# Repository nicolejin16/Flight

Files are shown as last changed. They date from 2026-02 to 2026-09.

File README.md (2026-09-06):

# SN
---
WRO documentation
<div align="center">
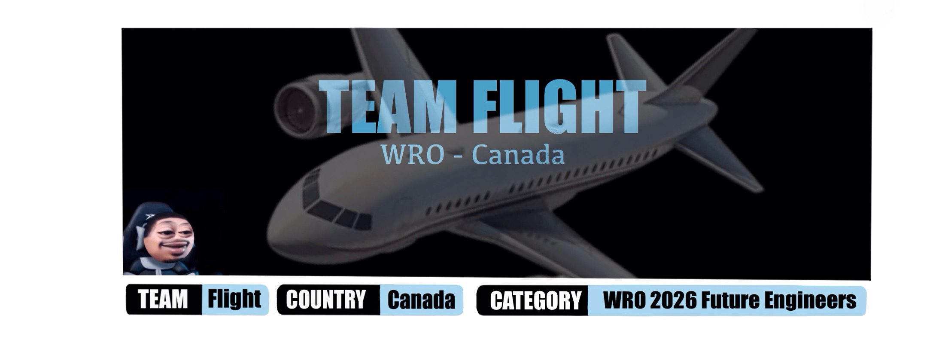
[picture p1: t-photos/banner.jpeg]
teamflightbanner

</div>

[WRO Engineering Journal 2026 - Nicole and Summer (PDF)](./Engineering%20Journal.pdf)

# Introduction
Team Flight is a group of high-school students from Ontario, Canada. This is our second year participating in WRO Future Engineers. We are passionate about robotics and is excited to compete in the open challenge and obstacle challenge for 2026. Our objective is to improve our score and documentation from last year and build a robot using hardware such as a LiDAR, Raspberry Pi 5, and new technology introduced to us like the Arduino Nano.

# Our coach
<table>
<tr>
  <td align="center" width="40%">
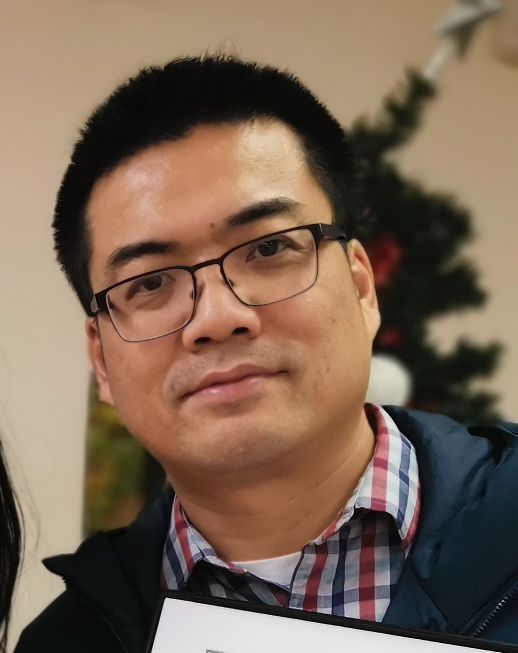
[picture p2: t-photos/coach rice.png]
    <br>
  </td>

  <td valign="top" width="60%">
 - Head coach of Robotics Competitions, including FLL (First LEGO League),  WRO (World Robotics Olympiad) Robo Sports, Future Engineers, and Robo Mission. Led teams in winning multiple national, international robotics, and programming awards. <br>
  - MSc in Electrical & Computer Engineering from the University of Alberta. <br>
  - BSc in Mathematics from Peking University.<br>
  - Founder of Explorer Robotics, a local robotics club in Ajax and Whitby, teaching coding, AI, robotics, etc.
  </td>
</tr>
</table>

# Team Members
---
<table width="100%" style="border:2px solid #FFC107; border-radius:12px; margin:12px 0;">
  <tr>
    <td width="28%" align="center" style="padding:12px; border-right:6px solid #111;">
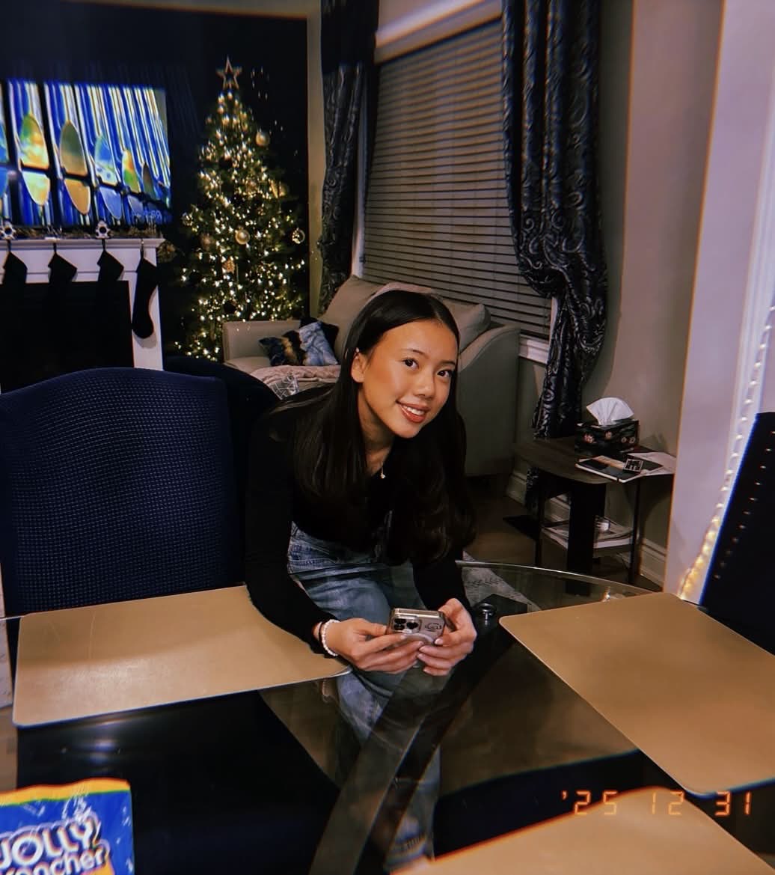
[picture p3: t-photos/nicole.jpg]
Nicole
    
    </td>
    <td width="72%" style="padding:12px 16px;">
      <h3 style="margin:0 0 6px 0;">Nicole - nicolejin27@gmail.com</h3>
      <p style="margin-top:8px;">
        <b>About Me:</b> My Name is Nicole, I am 16 years old. I am a figure skater and I also do badminton and track and field for my school. I have been involved in coding and Explorer Robotics since I was 8 and did WRO Future Engineers last year as well.
      </p>
    </td>
  </tr>
</table>

<table width="100%" style="border:2px solid #FFC107; border-radius:12px; margin:12px 0;">
  <tr>
    <td width="28%" align="center" style="padding:12px; border-right:6px solid #111;">
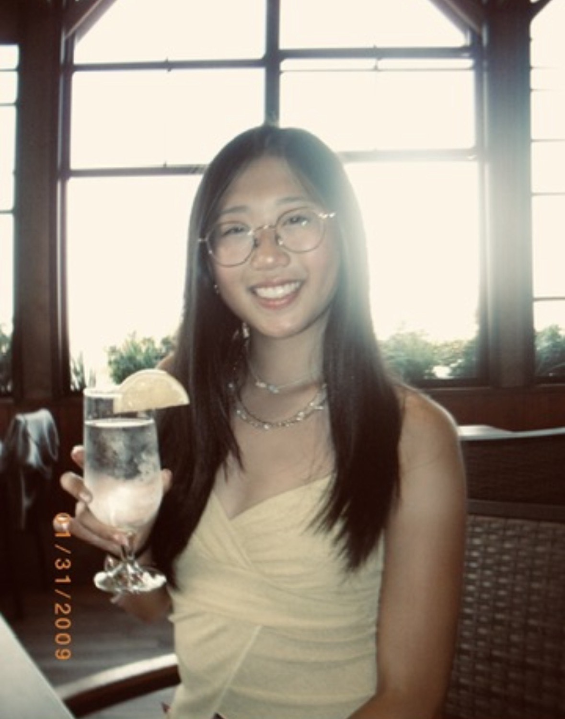
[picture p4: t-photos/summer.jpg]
Summer
    
    </td>
    <td width="72%" style="padding:12px 16px;">
      <h3 style="margin:0 0 6px 0;">Summer - summerlyu@gmail.com</h3>
      <p style="margin-top:8px;">
        <b>About Me:</b> My name is Summer, I am 17 years old. I love figure skating and drawing. I also do badminton, alpine skiing, and track and field for school. I starting coding when I was twelve years old and this is my second year doing WRO Future Engineers. 
      </p>
    </td>
  </tr>
</table>

# Team Photo

<table width="100%" style="border:2px solid #FFC107; border-radius:12px; margin:8px 0;">
  <tr>
    <td align="center" style="padding:14px;">
      <div style="border:2px dashed #FFC107; border-radius:10px; padding:24px; height:320px; display:flex; align-items:center; justify-content:center;">
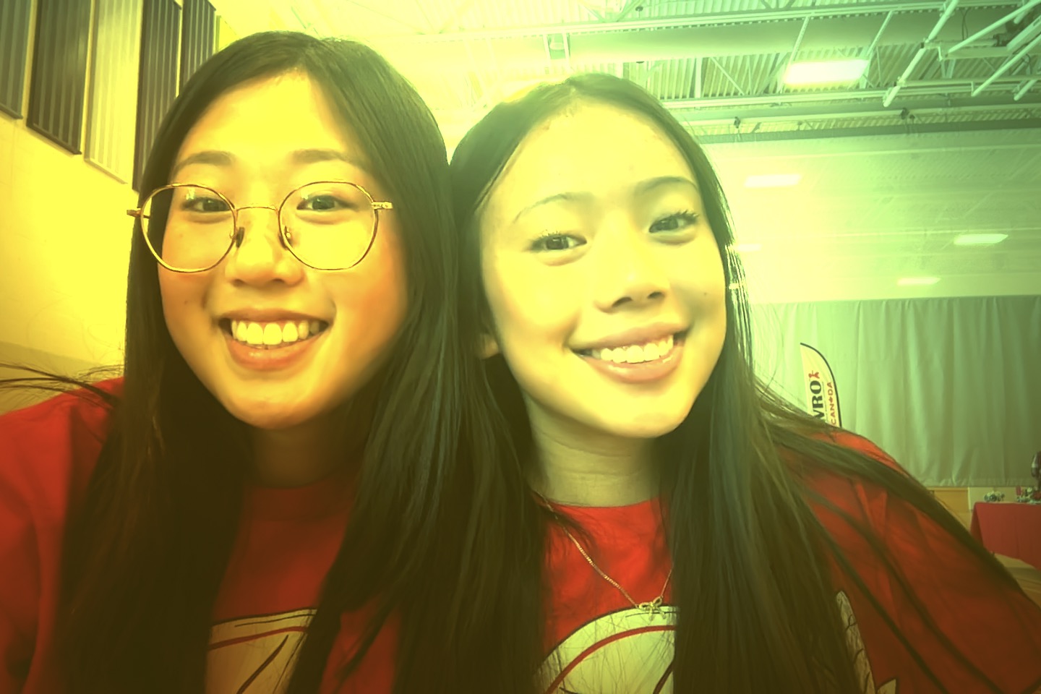
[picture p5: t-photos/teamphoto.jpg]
        <b></b>
      </div>
      <div style="margin-top:8px; color:#444;"><em>Team Flight</em></div>
    </td>
  </tr>
</table>

</div>

</br>
More team photos are provided in the "t-photos" folder. 

---

</br>

# Complete construction manual
The WRO Future Engineers is a competition for self-driven vehicles. Students need to design a model of a car, equip it with electromechanical components, and program it so that it can drive autonomously on the track, avoiding obstacles.
More details about the competition can be found on [the official site of WRO Association](https://wro-association.org/competition/2025-season/#rules).

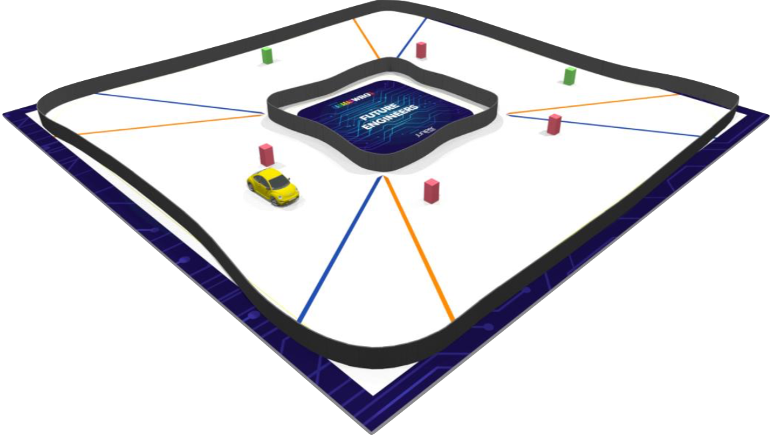
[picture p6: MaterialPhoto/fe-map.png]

The materials are intended to be built with the [Mkdocs](https://www.mkdocs.org/) site generator.

The example of the site is accessible [here](https://world-robot-olympiad-association.github.io/future-engineers-gs/)

# Hardware
---
| Name | Product | Price (CAD)|
| --- | --- | --- |
| RC Car Battery | [`Gens Ace 1300mAh Battery`](https://genstattu.com/gens-ace-1300mah-2s-7-4v-45c-g-tech-lipo-battery-pack-with-deans-plug/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) | $20.60 | 
| Drive Motor | [`Furitek Micro Komodo 1212 3450KV Brushless Motor`](https://furitek.com/products/furitek-micro-komodo-1212-3456kv-brushless-motor-with-15t-steel-pinion-for-fury-wagon-fx118) | $35.00 |
| Servo Motor | [`HS-5055MG 11.9g Metal Gear Digital Micro Servo`](https://hitecrcd.com/hs-5055mg-economy-metal-gear-feather-servo/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) | $25.00 |
| ESC | [`Furitek Lizard Pro 30A/50A ESC`](https://furitek.com/products/combo-of-furitek-lizard-pro-30a-50a-brushed-brushless-esc-for-axial-scx24-with-bluetooth) | $80.00 |
| Camera | [`5MP 1080P HD Camera with OV5647 Sensor`](https://www.amazon.ca/dp/B0D324RKRZ?ref=ppx_yo2ov_dt_b_fed_asin_title) | $35.00 |
| Raspberry Pi 5 8GB | [`Raspberry Pi 5`](https://www.amazon.ca/RasTech-Raspberry-Pi-refroidisseur-inclus/dp/B0DQX6JPVM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) | $250.00 |
| Arduino | [`Arduino Nano 33 BLE Rev2`](https://www.digikey.ca/en/products/detail/arduino/ABX00071/22478340) | $33.41 |
| Chassis | [`Gyro Version Drift car 1:24 scale`](https://www.aliexpress.com/item/1005010792530908.html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) | $163.05 | 
| LiDAR | [`LDROBOT D500 LiDAR Kit`](https://ca.robotshop.com/products/hiwonder-ld19-d500-lidar-developer-kit-360-dtof-laser-scanner-supports-ros1-2-raspberry-pi-jetson-nano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) | $149.99 |
| Button | [`2 Pin Panel Push Button`](https://www.amazon.ca/dp/B01J9KO7DC?ref=ppx_yo2ov_dt_b_fed_asin_title&th=1) | $12.99 |
| Switch | [`DC AC rocker switch`](https://www.amazon.ca/Suitable-125V-250V-Motorcycle-Disconnect-Dispenser/dp/B087PYW9BS) | $5.99 |
| Power regulator | [`Power supply expansion board for raspberry pi 5`](https://ca.robotshop.com/products/yahboom-power-supply-expansion-board-raspberry-pi-5) | $17.54 |

**Total:** $828.57
**With Tax:** $936.28

## Mobility

- [ESC](#ESC)
- [Servo motor](#Servo-motor)
- [Drive motor](#Drive-motor)
- [Power regulator](#Power-regulator)
- [Chassis](#Chassis)
- [Steering and Drive system](#Steering-and-drive-system)

## Power
- [RC car battery](#RC-car-battery)
- [Ratings and Wiring](#Ratings-and-wiring)

## Sensors and Perception
- [Camera](#Camera)
- [Raspberry pi 5](#Raspberrypi-5)
- [Arduino](#Arduino)
- [LiDAR](#LiDAR)

## Extra
- [Switch](#Switch)
- [Button](#Button)

## Code
- [Open Challenge](#Open-Challenge)
- [Obstacle Challenge](#Obstacle-Challenge)

# Mobility 

## ESC
<table>
<tr>
  <td valign="top" width="35%">

 ### Physical Qualities
  | Field          | Value                              |
  |----------------|------------------------------------|
  | **Product Title** | Furitek Lizard Pro 30A/50A ESC   |
  | **Size**          | 28 × 15.5 mm                     |
  | **Weight**        | 3.7 g                            |

  </td>

  <td width="65%" align="center">
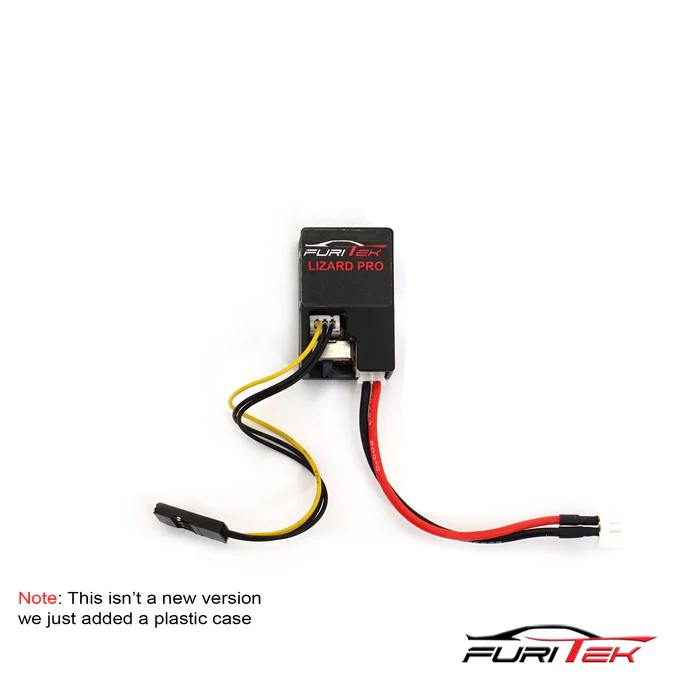
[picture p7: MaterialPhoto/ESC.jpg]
    <br>
    <em>Furitek Lizard Pro 30A/50A ESC</em>
  </td>
</tr>
</table>

### Why we chose this product

We chose Furitek Lizard Pro ESC because it controls the motors speed and ensure that voltage and current is safely delierved to the motor. It's small and manages direction on the open challenge and obstacle challenge. This ESC has a lightweight design, a high capacity and a reliable built-in BEC.

---

### Addtional information
- BIG BEC: **5V or 5V 2.5A**  
- Constant current : **30A**  
- Burst current: **50A**

[click here to return to links](#mobility)

## Servo motor
<table>
<tr>
  <td valign="top" width="35%">

### Physical Qualities
  | Field          | Value                                             |
  |----------------|---------------------------------------------------|
  | **Product Title** | HS-5055MG 11.9g Metal Gear Digital Micro Servo |
  | **Size**          | 0.89 x 0.45 x 0.94 inches                      |
  | **Weight**        | 9.5 grams                                      |
  | **Motor Type**    | 3 Pole Metal Brush Ferrite                     | 

  </td>

  <td width="65%" align="center">
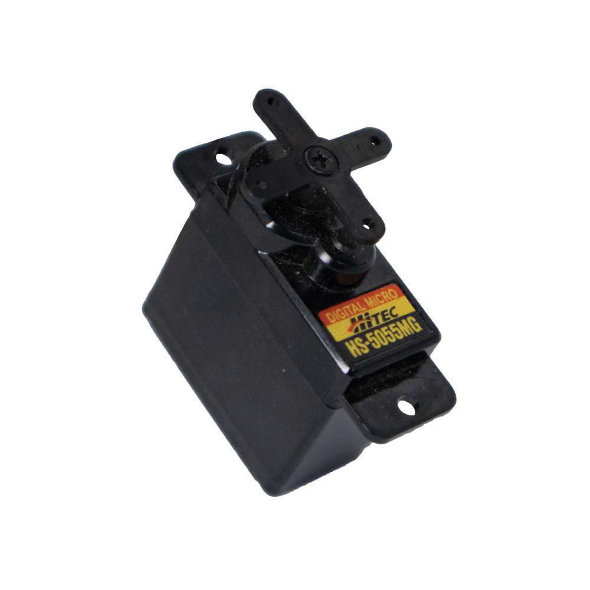
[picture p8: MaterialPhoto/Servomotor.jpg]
    <br>
    <em>HS-5055MG 11.9g Metal Gear Digital Micro Servo</em>
   </td>
</tr>
</table>

### Why we chose this motor 
We chose the Metal Gear digital Micro Servo because it has metal gears, which can withstand sustained high-speed voltage. It also has plastic casing around it which makes it light. Its compact and gives 1.3 ~ 1.6 kg./cm as maximum torque making it smooth and fast. 

### Additional information
- Operating Voltage Range: **4.8V ~ 6.0V**  
- Speed (Second @ 60°): **0.20 ~ 0.17**  
- Maximum Torque Range oz. / in.: **18 ~ 22**  
- No Load Operating Current draw: **120mA**    

</td>
</tr>
</table>

[click here to return to links](#mobility)

## Drive motor
<table>
<tr>
  <td valign="top" width="35%">

 ### Physical Qualities
  | Field          | Value                              |
  |----------------|------------------------------------|
  | **Product Title** | Furitek Micro Komodo 1212 3450KV |
  | **Size**          | 15.5 × 20.6 mm                   |
  | **Weight**        | 17.5 g                           |
  | **Physical State**| Brushless Outrunner (12-slot)    |

  </td>

  <td width="65%" align="center">
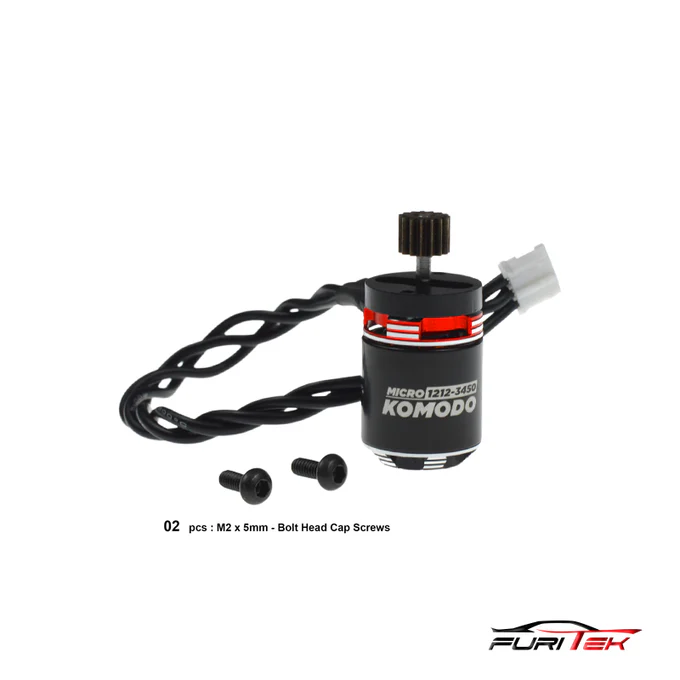
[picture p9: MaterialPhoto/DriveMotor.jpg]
    <br>
    <em>Furitek Komodo 1212 motor</em>
  </td>
</tr>
</table>

### Why we chose this motor 

We chose Furitek Micro Komodo brushless motor because its very compact and light-weight making it easier for our car to manouver. It distrbutes torque smoother and more evenly which helps less cogging and better control. 

---

### Addtional information
- KV: **3450 rpm/V**  
- No-load @10V: **0.7 A**  
- Power: **120 W**  
- Battery: **2–3S LiPo**  
- Resistance: **0.16 Ω**  
- Max Current: **10 A**  
- Slot/Pole: **12**  
- Shaft: **1.5 × 6 mm**

[click here to return to links](#mobility)

## Power regulator
<table>
<tr>
  <td valign="top" width="35%">

 ### Physical Qualities
  | Field          | Value                              |
  |----------------|------------------------------------|
  | **Product Title** |  Power supply Expansion board for Raspberry Pi 5  |
  | **Weight**        |      32g                           |
  | **Size**          |      65 by 56mm                 |

  </td>

  <td width="65%" align="center">
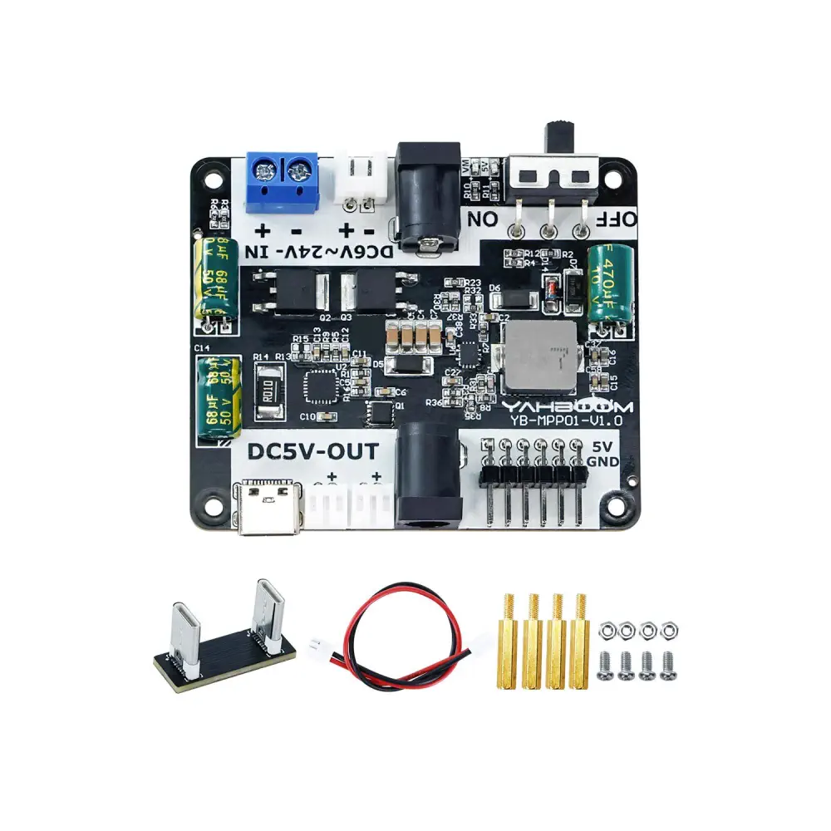
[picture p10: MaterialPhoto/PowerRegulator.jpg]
    <br>
    <em>Power regulator</em>
  </td>
</tr>
</table>

### Why we chose this product
We chose this power supply expansion board because it was tailor made for raspberry-pi. It has many input and output ports and it has efficient voltage stabilization technology, ensuring that the input power supply is stably adjusted for the 5V/5A output, which meets the power needs for the raspberry pi perfectly. Using this power regulator prevents potential low-voltage operation risks and USB interface current limitation. It can also stack directly onto the raspberry pi with screw copper posts, which makes our car more compacts and easier to turn. 

---

### Addtional information
- Voltage input: **6~24V**
- Voltage output: **5V/3A (6V Input), 5V/5A (7~24V input)**
-  Output interference: **Type-C, PH2.0-2pin*2, DC5.5*2.1, 2*6pim Bent pin header**
-  Through hole diameter: **M2.5mm**

[click here to return to links](#mobility)

## Chassis
<table>
<tr>
  <td valign="top" width="35%">

 ### Physical Qualities
  | Field          | Value                              |
  |----------------|------------------------------------|
  | **Product Title** |    RC Drift Car 1:24 Scale |
  | **Weight**        |      110g                           |
  | **Size**          |       21 x 9.5 x 6 cm               |

  </td>

  <td width="65%" align="center">
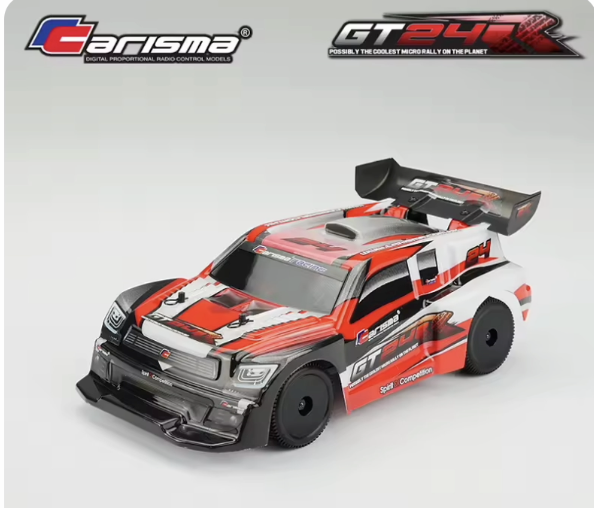
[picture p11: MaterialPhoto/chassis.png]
    <br>
    <em>  RC Drift Car 1:24 Scale</em>
  </td>
</tr>
</table>

### Why we chose this product
We chose this chassis because it was easy to take apart and use as a sturdy base for our robot. It was lightweight and many parts could easily be taken apart to make space for the motors and battery to fit inside. Its dimensions are long enough to include every component, but doesn't hinder the functionality of the robot. The wheels are made of grippy materials, making the robot be able to turn easily and with accuracy. The base if flat, making it easy to mount our 3D printed pieces that hold up our camera and raspberry Pi. 

### Placement choice for components
- The camera is placed at a level where it's able to see incoming walls, pillars, and obstacles at a reasonable distance without being to high causing an imbalance. It's placed at an angle where it includes the space in front of the robot, but not what on the robot.
- The LiDAR is placed at the front of the robot to ensure it is detected well in advance so our robot is prepare to avoid the oncoming obstacle from all directions. By placing it in the front, it doesn't need to calculate the difference between the obstacle and the bumper. Placing the LiDAR at a low point prevents anything from blocking the sensors. 
- By putting the motors, esc, and battery close together under the raspberry Pi, it reduces the amount of wires around the robot, making it more organized and clean. We can also place the wires underneath, saving space and preventing it from getting in the way or getting loose.

---

### Addtional information
- Ranging Distance: **0.03-12m**

[click here to return to links](#mobility)

## Steering and drive system
### Steering
Our chassis didn't have a large enough steering angle, but with many adjustments, we hollowed a larger compartment and cut limitations so our chassis can turn sharper around pillars and corners. In the hollowed compartment, we put both our motors, keeping it compact and saving space. 

- Both left and right wheels turn at the same angle, reducing imbalance and oversteering.
- By keeping it compact more of the weight is focused lower, making uncontrolled movement minimized and more predictable steering.
- Larger steering angle makes last minute navigation easier around pillars and walls. 

### How the car moves 

When the battery provides power, the ESC manages the electricity sent to the motor. The motor turns this controlled flow of electricity into rotational motion, which makes the car's wheels spin. By changing the voltage and current through the ESC, we can control the car's speed and direction, enabling it to move forward, backward, accelerate, slow down, or reverse.

At the same time, the servo motor handles steering. It changes the angle of the front wheels through the steering system, allowing the car to turn left or right accurately.

### Drive system 
Our car uses a real whieel drive (RWD), meaning that the motor's power is transmitted to the back wheels rather than the front. This configuration provides many benefits to the car:
- Better weight distribution. The front wheels handle all the steering, and the rear wheels help with propulsion, whith helps the car remain more balanced when accelerating and turning. 
- Provides a stronger grip on surfaces such as the map. Since the rear of the robot has more weight, the back wheels get pressed down into the ground more, providing more traction and grip. 
- The front wheels are used only for steering, this is so the car can turn more precisely aince theres no interference from the motor. 
<br>

[click here to return to links](#mobility)
# Power

## RC car battery
<table>
<tr>
  <td valign="top" width="35%">

  ### Physical Qualities
  | Field | Value |
  |--------|--------|
  | Product Title | Gens Ace 1300mAh 2S 7.4V 25C LiPo |
  | Size | 70.9 × 35.2 × 14.5 mm |
  | Weight | 90 g |

  </td>

  <td align="center" width="65%">
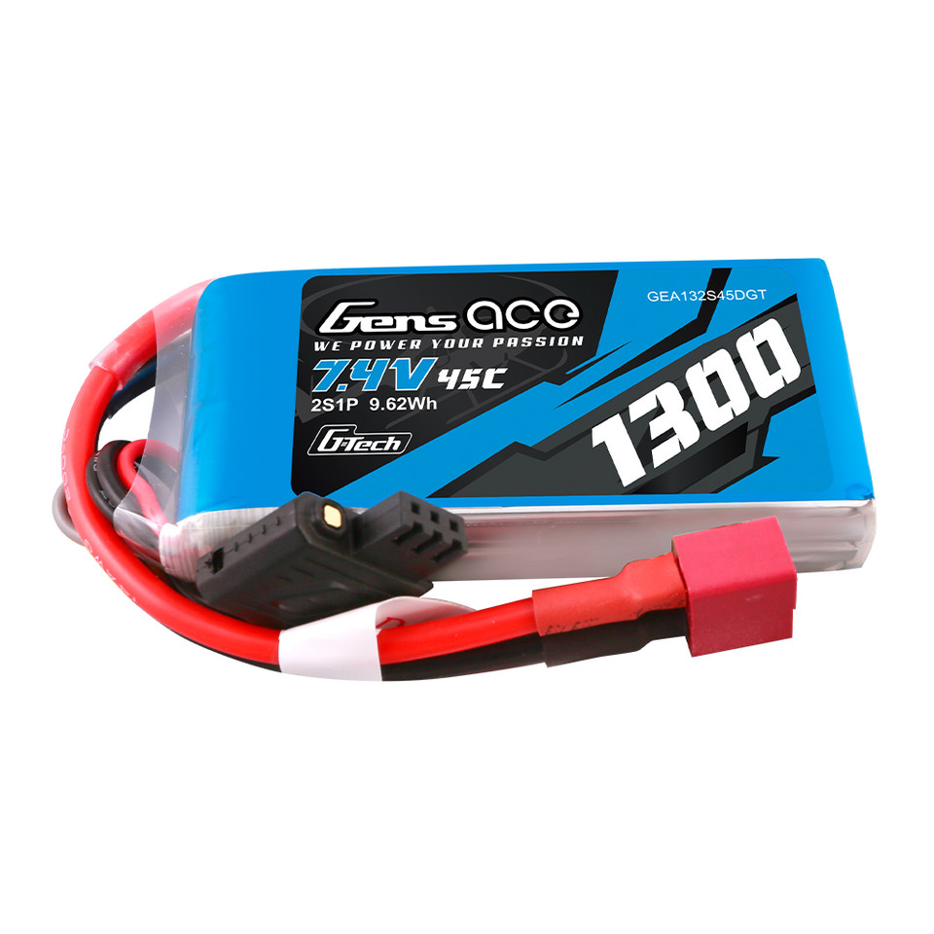
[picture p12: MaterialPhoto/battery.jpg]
    <br>
    <em>Gens Ace 1300mAh 2S LiPo Battery</em>
  </td>
</tr>
</table>

### Why we chose this battery
We chose the Gens Ace Battery because its lightweight and provides a long run time between charges. 
It allows us to keep the self-driving car well balanced which is optimal for the obstacle challenge and open challenge. 
The 7.4V gives good acceleration without noticeable voltage drop and offers stable power delivery without extra wear. 

---

### Additional information
- Voltage: **7.4V**  
- Capacity: **1300mAh**  
- Discharge Rate: **45C Continuous / 90C Peak**  
- Charge Rate: **5C (6.5A Max)**
- Cell Configuration: **2S1P**  
- Watt Hours: **9.62Wh**  

The battery is secured to our robot by tape on the bottom. <br>
[click here to return to links](#mobility)

---

##  Ratings and wiring

### Power ratings table

| Component | Voltage | Normal Current Draw | Max Current Draw | Normal Power | Max Power |
|-|-|-|-|-|-|
| Camera | 5 V | 0.16 A | 0.20 A | 0.80 W  | 1.00 W  |
| Furitek Lizard Pro ESC | 7.4 V | 0.007 A  | 0.10 A | 0.05 W  | 0.74 W  |
| Furitek Micro Komodo Motor  | 7.4 V | 0.95 A | 10.0 A | 7.00 W  | 74.0 W  |
|  Servo Motor | 5 V | 0.10 A | 0.70 A | 0.50 W  | 3.50 W  |
| MicroSD, LEDs, | 5 V | 0.12 A | 0.30 A | 0.60 W  | 1.50 W  |
| Raspberry Pi 5 | 5 V | 0.55 A | 2.00 A | 2.75 W  | 10.0 W  |
| Expansion Board | 5 V | 0.12 A | 0.50 A | 0.60 W  | 2.50 W  |

<br>

Our Gens Ace 1300 mAh 7.4V  Lipo Battery provides plenty of power to our car as shown in the power ratings table above/ 
This will ensure that all our properties will run smoothly and provide stable voltage for the Raspberry Pi, controller, sensors, and periherals. <br>

**Estimated runtime (Idle/bench testing):** 45-60 minutes 
- The robot is stationary. The LiDAR is actively scanning, the camera is streaming, the Pi is idle or listening for commands, and the servo is holding its position.
- Logic Load (i.e. camera, Pi, arduino): 1.2A @ 5V (6.0W)
- Mechanical Load (i.e. servo): 0.1A @ 5V (0.5W)
- Total Power Consumption: 6.5W <br>

**Estimated runtime (Active driving run):** 20-28 minutes 
- Logic load (Pi is working harder): 1.8A @5V (9.0W)
- Mechanical Load (Motor moving + steering adjustments): 2.0A @ battery voltage (Avg. approx 18W)
- Total Power Consumption: 27.0W <br>
**Estimated runtime (Heavy/High Load):** 18-22 minutes 
- Logic Load (using max Pi and camera utilization): 2.4A @ 5V (12.0W)
- Mechanical Load (Heavy motor draw + hard servo cornering): 6.0A continuous average @ battery voltage (approx 55W - 65W)
- Total Power Consumption: 72.0W <br> <br>
### Electrical wiring
<div algn="center">
<table>
  <tr>
    <td style="border: 200px solid black; padding: 5px;">
      
    </td>
  </tr>
</table>

</div>

### Components

- Raspberry Pi 5
- Expansion Board
- Camera
- Servo Motor
- ESC (Electronic Speed Controller)
- Motor
- Battery
- Switch

[click here to return to links](#mobility)

# Sensors and Perception

## Camera
<table>
<tr>
  <td valign="top" width="35%">

 ### Physical Qualities
  | Field          | Value                              |
  |----------------|------------------------------------|
  | **Product Title** | 5/Zero Camera Module (OV5647 Sensor)   |
  | **Cable**         | 15 cm Ribbon Cable                     |
  | **Weight**        | 20 g                                   |
  | **Size**          | 11.6 x 6.6 x 3.7 cm                    |

  </td>

  <td width="65%" align="center">
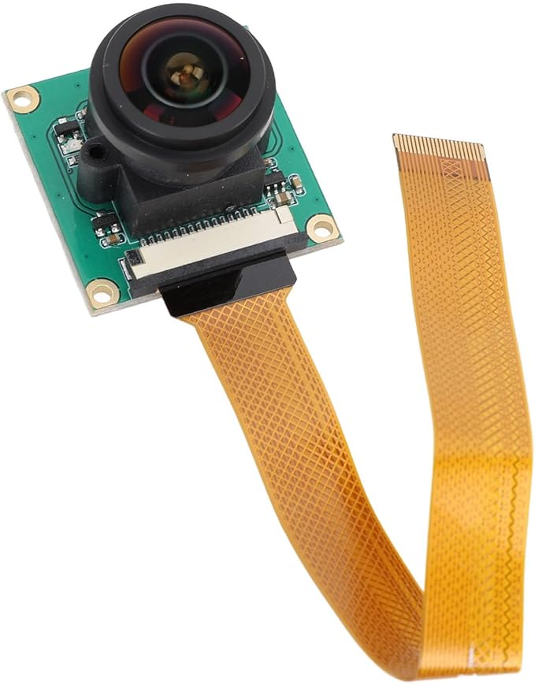
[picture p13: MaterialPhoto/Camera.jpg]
    <br>
    <em>5/Zero Camera Module (OV5647 Sensor)</em>
  </td>
</tr>
</table>

### Why we chose this product

We chose the 5/Zero Camera Module because we can use the wide angle camera lens to track the regions of interest and limit the amount of blind spots during the open challenge. It's 175° lens is good for wall detection and true to life colors with automatic light adjustment. It's very compatible with the raspberry pi and easy to install. It can withstand heat up to 70° celcius, making it suitable when we need to use it for longer periods of time. 

---

### Addtional information
- Material: **ABS+ Optimal glass**  
- Lens Pixel : **5MP**  
- Focal Length: **3.6mm**
- Lens Angle: **175°**
- CMOS Size: **1/2.5inch**
- Resolution: **2592x1944**

[click here to return to links](#mobility)

## Raspberrypi 5
<table>
<tr>
  <td valign="top" width="35%">

 ### Physical Qualities
  | Field          | Value                              |
  |----------------|------------------------------------|
  | **Product Title** | RasTech Raspberry Pi 5 Kit (8GB RAM)   |
  | **Weight**        | 70 g                                  |
  | **Size**          | 15 x 9.9 x 3.9 cm                      |
  | **Comes with**    | Pi 5 Board, Case, Active Cooler, Screwdriver |

  </td>

  <td width="65%" align="center">
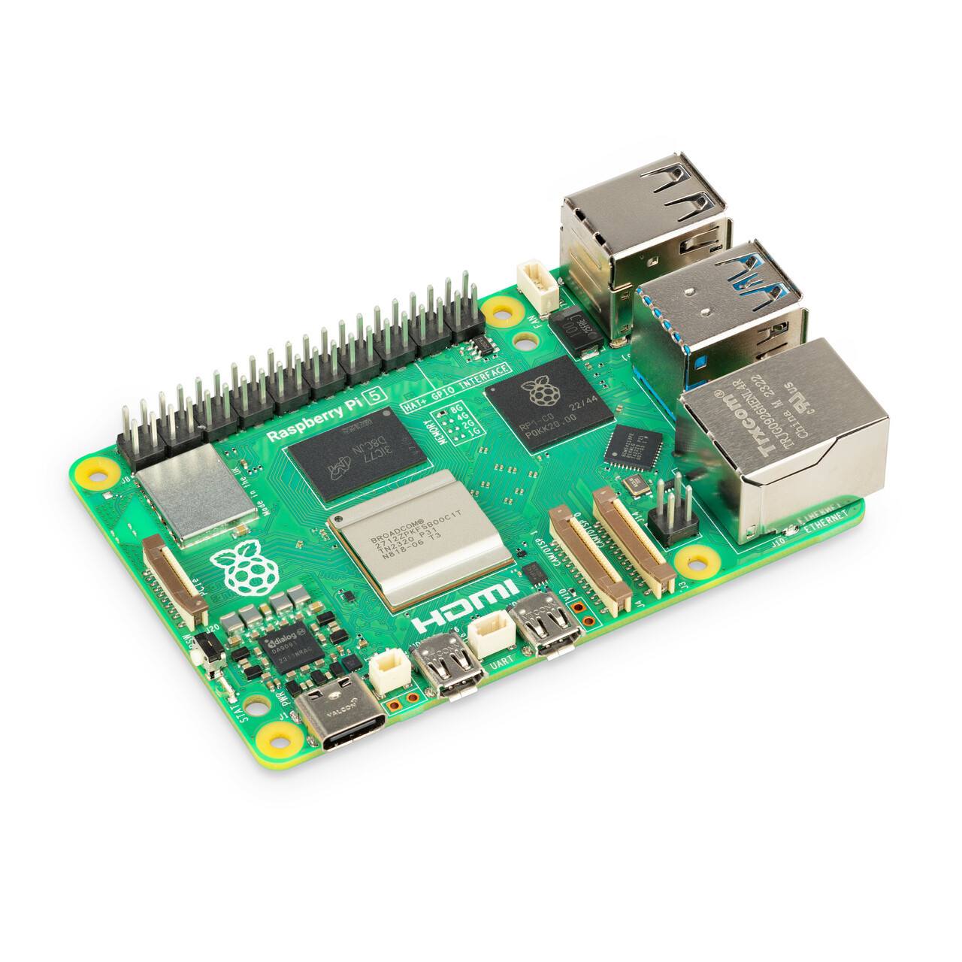
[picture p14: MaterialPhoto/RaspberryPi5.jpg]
    <br>
    <em>RasTech Raspberry Pi 5 Kit (8GB RAM)</em>
  </td>
</tr>
</table>

### Why we chose this product

The main part of our robot is the Raspberry Pi 5 and it controls the computer vision and LiDAR data interpretation. It is perfect for energy comsumption and processing power, making it suitable for running our Python codes for the open challenge and obstacle challenge. 

---

### Addtional information
- Manufacturer: **Vemico**  
- Wireless : **802.11ac Wi-Fi, Bluetooth**  
- Processor: **Broadcome BCM2712, Quad-Core Cortex-A76 @ 2.4 GHz**
- RAM: **8 GB LPDDR4X-4266**
- GPU: **VideoCore VII (Integrated)**
- Storage: **microSD**
- Ports: **2x USB 3.0, 2x USB 2.0, 2x micro HDMI, Ethernet, GPIO**
- OS: **Raspberry Pi OS**

[click here to return to links](#mobility)
  
## Arduino
<table>
<tr>
  <td valign="top" width="35%">

 ### Physical Qualities
  | Field          | Value                              |
  |----------------|------------------------------------|
  | **Product Title** |   Arduino nano 33 BLE REV2 |
  | **Weight**        |  5g                                  |
  | **Size**          |   45mm x 18mm                 |

  </td>

  <td width="65%" align="center">
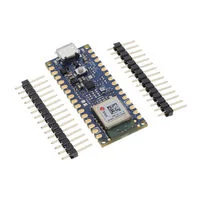
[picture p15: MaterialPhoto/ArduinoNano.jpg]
    <br>
    <em> Arduino nano 33 BLE REV2</em>
  </td>
</tr>
</table>

### Why we chose this product
The 4 PWM pins makes it versatile for various embedded applications/ It's super compatible with the arduino IDE, making the programming smooth and seamless. It weighs only 5 grams which minimizes load on the chassis, allowing for better acceleration and agility. 

### How the arduino and raspberry Pi communicate
The Raspberry Pi handles the LiDAR's mapping, vision processing, and path planning while offloading low-level GPIO operations (ESC PWM signaling, steering servo adjustments, wheel encoder interrupts) to the Nano. Connecting the Arduino Nano directly to the Pi 5's USB 3.0 port provides both power and a clean USB-Serial interface without needing external voltage level shifters. The Pi 5's GPIO pins strictly operate at 3.3V. Interfacing 5V sensors directly through the Nano's native 5V-tolerant analog/digital pins prevents accidental overvoltage damage to the Pi. 

---

### Addtional information
- Logic level voltage: **3.3V**
- Input voltage: **5V to 18V**
- Digital I/O Pins: **14**
- Clock speed: **64 MHz**
- Flash memory: **1MB**

After we soldered the arduino, it was secured tightly to our robot using double sided tape on the USB ports of the raspberry pi. <br>
[click here to return to links](#mobility)

## LiDAR
<table>
<tr>
  <td valign="top" width="35%">

 ### Physical Qualities
  | Field          | Value                              |
  |----------------|------------------------------------|
  | **Product Title** | LDROBOT D500 LiDAR   |
  | **Weight**        | 45 g                                  |
  | **Size**          | 54 × 46.3 × 35 mm                     |

  </td>

  <td width="65%" align="center">
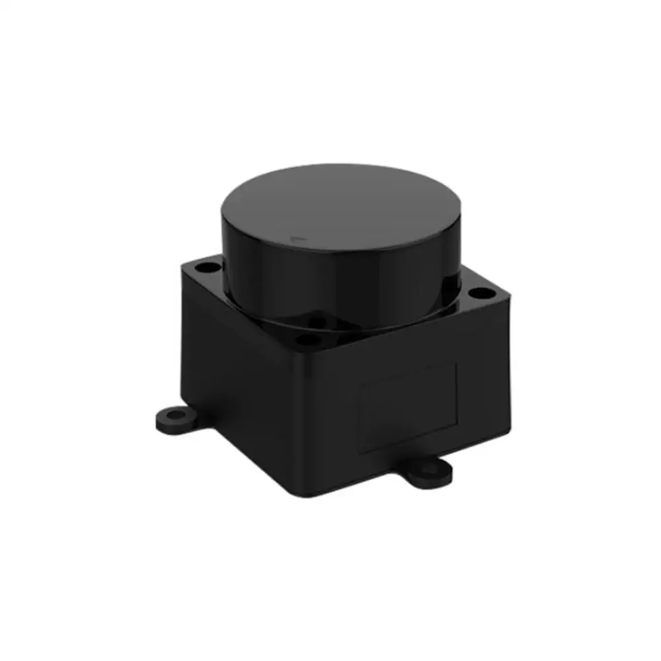
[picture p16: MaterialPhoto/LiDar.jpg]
    <br>
    <em>LDROBOT D500 LiDAR </em>
  </td>
</tr>
</table>

### Why we chose this product

 We are going to use the LDROBOT D500 LiDAR for obstacle challenge because it provides accurate range data in every direction up to 12 meters. We are also switching to use the LiDAR instead of the camera because it doesn't depend of good lighting to function properly. With its long scanning range, it can detect obstacles further away and then turn accordingly. 

### Parking
We have planned on using the LiDAR for the parallel park section at the beginning and end of the obstacle challenge, but we haven't had the change to progress that far this year. We have the placement and layout for the use of the LiDAR and we will continue to work on its use and progression in the future. So, we are not going to be using the LiDAr for the obstacle challenge this year. 

---

### Addtional information
- Ranging Distance: **0.03-12m**  
- Accuracy : **±10 mm (0.3–0.5 m), ±20 mm (0.5–2 m), ±30 mm (2–12 m)**  
- Scanning Angle: **360°**
- Scanning frequency: **6-13 Hz**
- Ranging frequency: **5000Hz**
- Wavelength: **895 – 915 nm (Typ. 905 nm)**
- Interface: **UART @ 230400 baud**
- Ambient Light Tolerance: **up to 60k Lux**
- Power Supply: **5V**
- Power Comsumption: **1.45W (290 mA)**
- Operating Temp: **-10° to 45° C**

[click here to return to links](#mobility)

# Extra
  
## Button
<table>
<tr>
  <td valign="top" width="35%">

 | Field          | Value                              |
  |----------------|------------------------------------|
  | **Product Title** |   2 Pin Panel Push Button |
  | **Weight**        |            22.68 g                |
  | **Size**          |     16.51 x 0.51 x 0.51 cm   |
  |**Brand**          |   MakerSpot  |
  | **Material**      |  tile |

  </td>

  <td width="65%" align="center">
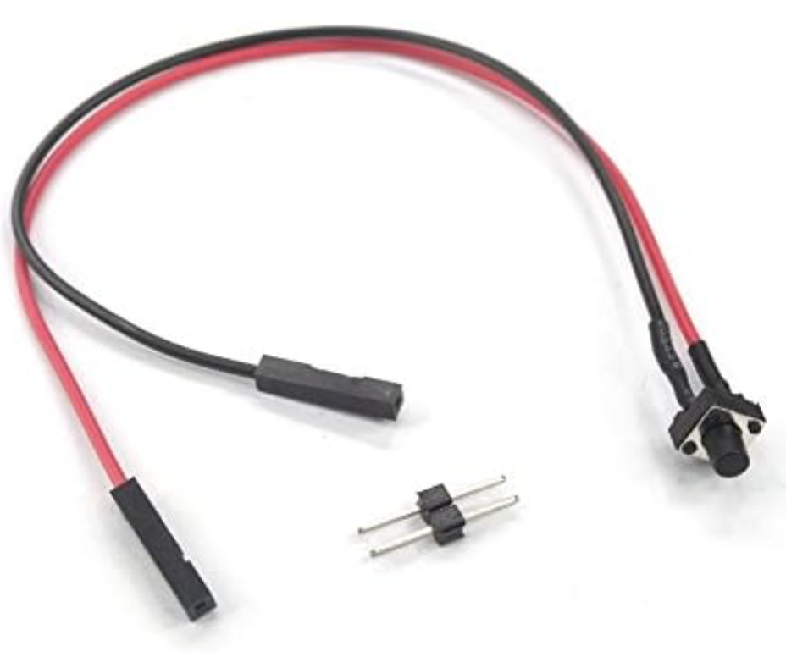
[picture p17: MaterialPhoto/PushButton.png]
    <br>
    <em>2 pin push button</em>
  </td>
</tr>
</table>

### Why we chose this product
We chose this button for our raspberry Pi because it's very simple yet easy incorporate onto our robot. Since adding this button was a last minute detail, it's lightweight and small design allows an easy attachment without getting in the way of the other robot components. 

---

### Addtional information
- Current rating: **50 milliamps**
- Terminal: **solder**
- Contact material: **copper**
- Mounting type: **through hole mount**
- Operating mode: **manual**
  
[click here to return to links](#mobility)
## Switch
<table>
<tr>
  <td valign="top" width="35%">

 | Field          | Value                              |
  |----------------|------------------------------------|
  | **Product Title** |  DC AC rocker switch  |
  | **Weight**        |        4g                    |
  | **Size**          |    1.1cm by 2.1cm by 1.5cm      |
  |**Brand**          |  	EKYLIN   |
  |**Material**       | Metal, plastic  |

  </td>

  <td width="65%" align="center">
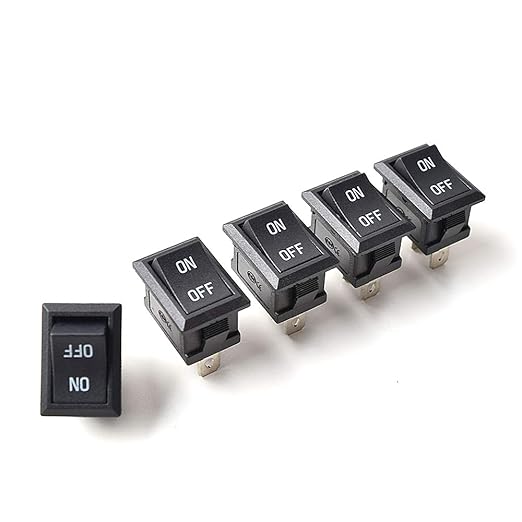
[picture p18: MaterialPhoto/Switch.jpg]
    <br>
    <em>DC AC rocker switch</em>
  </td>
</tr>
</table>

### Why we chose this product
We choose this switch because it was simple and easy to install. This switch is suitable for AC 125V 10A, AC 250V 6A, DC 12V 20A, DC 24V 10A, DC 36V 6.5A. It was made by an insulated plastic and copper pins, with a mechanical life of more than 8 thousand cycles and an electrical life of more than 10 thousand. The high operating temperature allows it to still work and function properly when it is used for an extended period of time. 

---

### Addtional information
- Current rating: **10 amps**
- Operating voltage:**125 Volts (AC)**
- Insulation resistance: **100MΩ min**
- Operating temperature: **-25°C~85°C**

[click here to return to links](#mobility)

# Tools and Equipment
| Name | Product | Price (CAD)|
| --- | --- | --- |
| 3D Printer | [`Bambu Lab X1 Carbon 3D Printer`](https://genstattu.com/gens-ace-1300mah-2s-7-4v-45c-g-tech-lipo-battery-pack-with-deans-plug/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) | $1289 | 
| Soldering Kit| [`TOAUTO DS90 Soldering Station`](https://www.amazon.ca/FASTTOBUY-Soldering-Station-194%C2%B0F-896%C2%B0F-Temperature/dp/B082HP4513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) | $90 |
| Screws, Screwdriver, Pliers, etc. | n/a | $~35 |  
| Fillament 1kg | [`EconoFil™ Standard PLA Filament`](https://www.inksmith.ca/collections/filament/products/econofil-standard-pla-filament-black-1-75mm-1-kg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) | $26 |  

**Total:** $~1440 *No Tax*

**With Tax:** $~1627.2

# 3D design and fabrication

| *Component that holds the raspberry pi, arduino and power regulator* | <br>
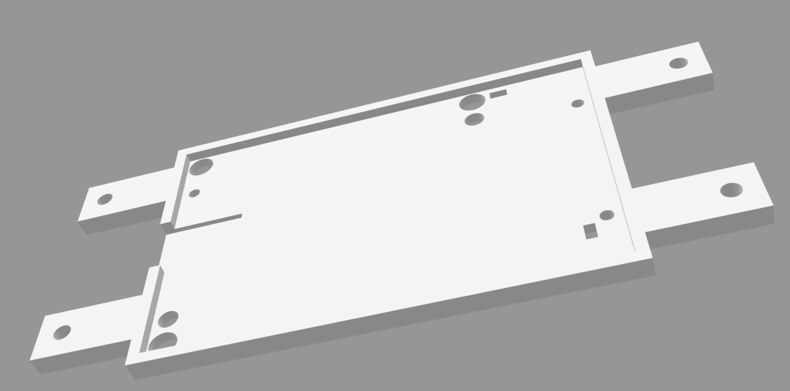
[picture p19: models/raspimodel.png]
 <br>
| *Component that holds the camera up*| <br>
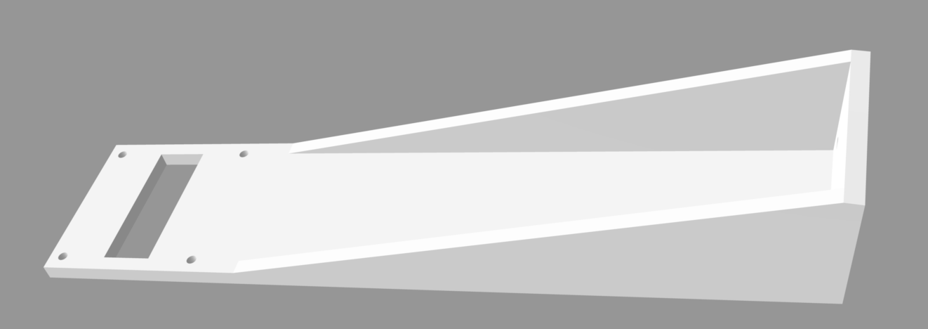
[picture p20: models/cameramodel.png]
  <br>

Full interactive models provided in the "models" folder. <br>

### Overview
- a main part of our project was the 3D print which allowed us to design and refine custom parts of our chassis for best results
- Our 3D print held major components to the function of our robot like the arduino, raspberry pi, power regulator, camera, and liDar.
- Fabrication in Onshape, printing using Prusa MK4 with PLA filament

### Printing information

| Setting | Value |
|---|---|
| Printer | [`Prusa MK4`](https://www.prusa3d.com/product/original-prusa-mk4s/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) |
| Material | PLA |
| Nozzle Temperature | 230 °C |
| Bed Temperature | 65 °C (Textured PEI Plate) |
| Filament Diameter | 1.75 mm |
| Flow Ratio | 0.96 |
| Max Volumetric Speed | 12 mm³/s |
| Layer Height | 0.2 mm |
| Nozzle Diameter | 0.4 mm |
| Infill Density | 15 % |

We chose PLA because of it's easy accessibility and affordable cost, allowing quick iteration without sacrificing accuracy. It's proformance is reliable, and it is easy to print again if there was a mistake. 

### Photo gallery 
<table>
  <tr>
    <td align="center" style="border:1px solid #ddd; padding:15px;">
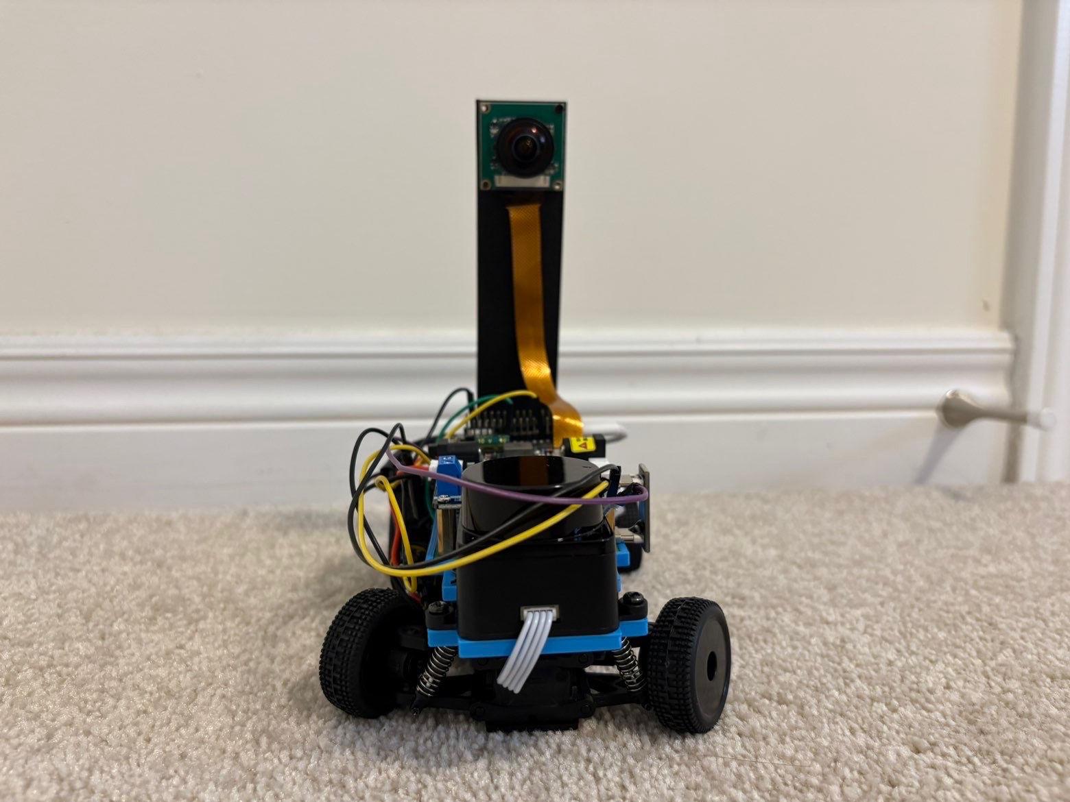
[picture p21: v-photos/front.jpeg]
    <br/>
      <em><strong>Front View </strong></em>
    </td>
    <td align="center" style="border:1px solid #ddd; padding:15px;">
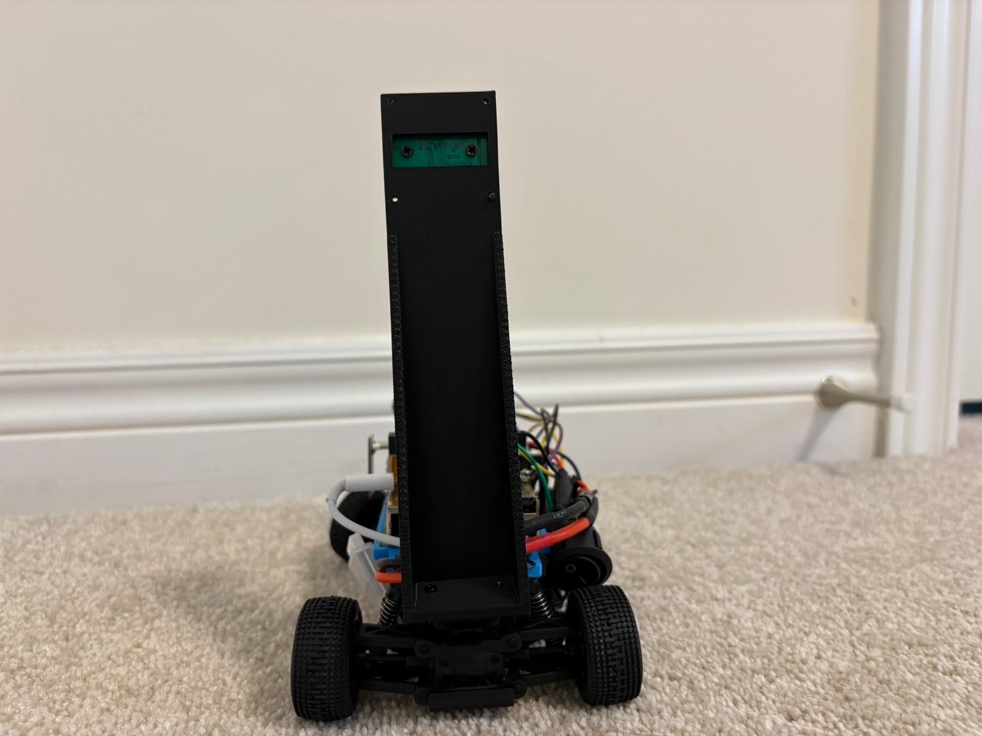
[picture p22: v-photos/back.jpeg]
      <br/>
      <em><strong>Back view</strong></em>
    </td>
    <td align="center" style="border:1px solid #ddd; padding:15px;">
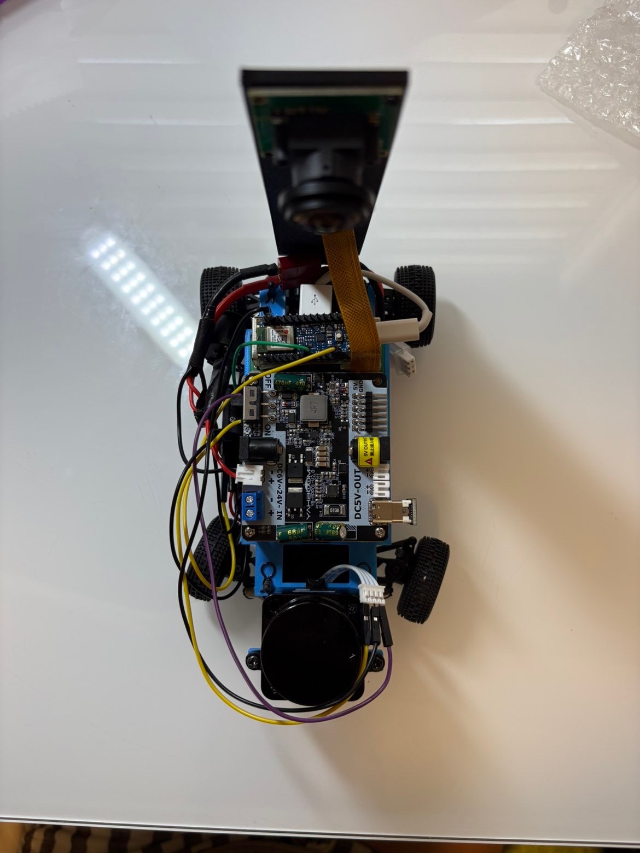
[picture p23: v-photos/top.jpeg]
     <br/>
      <em><strong>Top View</strong></em>
    </td>
  </tr>
  <tr>
    <td align="center" style="border:1px solid #ddd; padding:15px;">
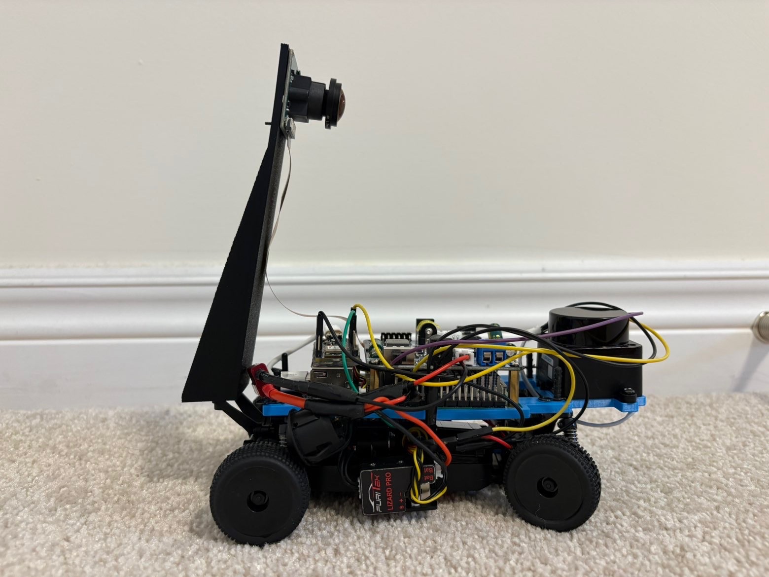
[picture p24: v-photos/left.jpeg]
     <br/>
      <em><strong>Left Side View</strong></em>
    </td>
    <td align="center" style="border:1px solid #ddd; padding:15px;">
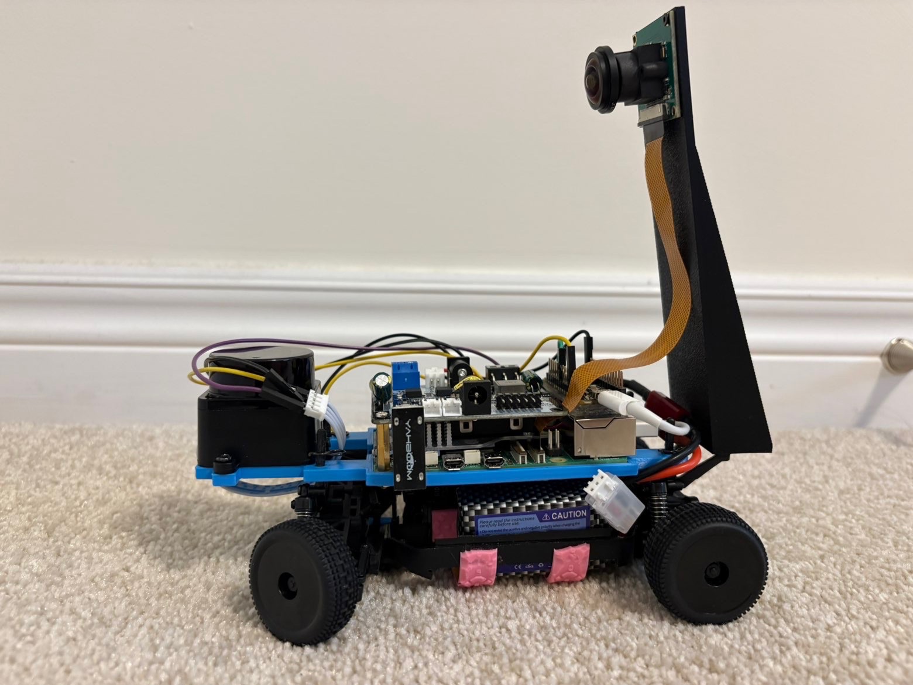
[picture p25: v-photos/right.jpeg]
      <br/>
      <em><strong>Right Side View</strong></em>
    </td>
    <td align="center" style="border:1px solid #ddd; padding:15px;">
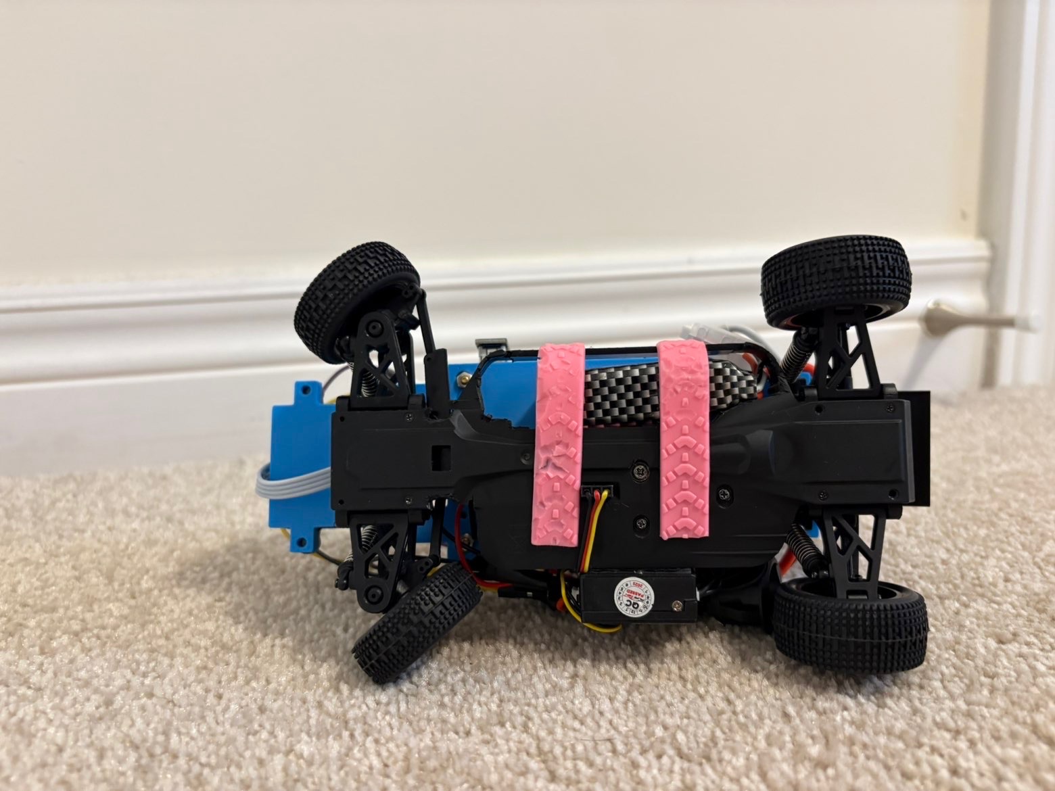
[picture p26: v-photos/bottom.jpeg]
      <br/>
      <em><strong>Bottom View</strong></em>
    </td>
  </tr>
</table>
<br>
---

# Open Challenge
## Overview
The Open Challenge is designed to test a robot’s ability to autonomously navigate a closed-loop course using only the black walls as guidance. The robot must detect walls, align itself, make smooth turns at corners, and complete 3 laps without manual intervention in under 3 minutes. The main focus is on path-following and code accuracy. Visit the Youtube video linked below for more in-depth information. <br>

**Youtube Link:** <br>
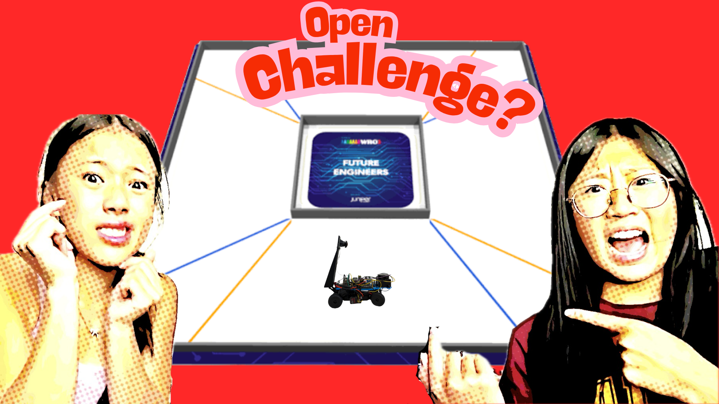
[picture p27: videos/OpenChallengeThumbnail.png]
Team Flight Open Challenge 2026
 <br>
<a href="https://youtu.be/M6A6o3CX_g0">Team Flight Open Challenge 2026 </a> 

---

### Game Map

<table>
  <tr>
    <td style="border: 200px solid black; padding: 5px;">
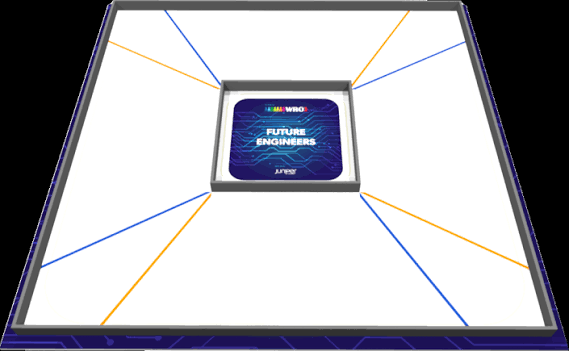
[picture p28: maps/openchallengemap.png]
      
    </td>
  </tr>
</table>

## Code
```
import sys
import time
import threading
import subprocess
import cv2
import numpy as np
from picamera2 import Picamera2
import os
import signal
import serial
from enum import Enum

def send(cmd):
    try:
        arduino.write(cmd)
        #print(cmd)
    except serial.SerialTimeoutException:
        arduino.reset_output_buffer()
        try:
            arduino.write(cmd)
        except serial.SerialTimeoutException:
            print("not working")

class State(Enum):
    WALL_FOLLOW = 1
    CORNER_TURN = 2

state = State.WALL_FOLLOW

prev_error = 0

# Debounce
trigger_count_left = 0
trigger_count_right = 0
TRIGGER_FRAMES = 5

# Trigger memory
#trigger_side = None  # "left", "right"

# Timing

corner_start_time = 0
MIN_CORNER_TIME = 2

# IMU heading tracking
last_heading_time = time.time()
HEADING_INTERVAL = 1.0 # request heading from Arduino every 1 second
imu_heading = 0.0

# Handle debug mode
n = len(sys.argv)
debugMode = 1
if n > 1 and sys.argv[1] == "Debug":
    debugMode = 1

arduino = serial.Serial('/dev/ttyACM0', 115200, timeout=1, write_timeout = 0.05)
time.sleep(2)

# Initialize the camera
picam2 = Picamera2()
picam2.preview_configuration.main.size = (700, 480)
picam2.preview_configuration.main.format = "RGB888"
picam2.preview_configuration.controls.FrameRate = 30
picam2.configure("preview")
picam2.start()
#time.sleep(1)

center_servo = 90
min_servo = 60
max_servo = 120

# Proportional gain constant 
Kp = 0.009
Kd = 0

counter = 0

lower_black = np.array([0, 0, 0])
upper_black = np.array([180, 255, 100])

lower_orange = np.array([88, 56, 107])
upper_orange = np.array([116, 224, 255])

lower_blue = np.array([0, 97, 88])
upper_blue = np.array([19, 255, 255])
# Regions of interest
roiLeft = (20, 220, 200, 80)
roiRight = (500, 220, 200, 80)
roiOrange = (220, 300, 240, 50)
roiBlue = (220, 300, 240, 50)
# Start motor
send(b'@M1630\n')
send(b'@S90\n')

orange = 0
orange_line_detected = False
last_orange_time = time.time()
blue = 0
blue_line_detected = False
last_blue_time = time.time()

turning_angle = 0

cooldown_seconds = 3

while True:
    now = time.monotonic()
    
    frame = picam2.capture_array()

        # Periodically request IMU heading from Arduino
    if time.time() - last_heading_time >= HEADING_INTERVAL:
        send(b'@H\n')
        last_heading_time = time.time()
        time.sleep(0.02) # brief wait so response arrives before we read
    # Read and process all incoming serial data
    if arduino.in_waiting > 0:
        try:
            raw = arduino.read(arduino.in_waiting).decode('utf-8', errors='ignore')
            for line in raw.splitlines():
                line = line.strip()
                if not line:
                    continue
                try:
                    imu_heading = float(line)
                    #print(f'[IMU Heading] {imu_heading:.2f}°')
                except ValueError:
                    pass # ignore any non-numeric lines
        except Exception:
            pass # silently ignore malformed or partial data
    
    if arduino.in_waiting > 0:
        arduino.read(arduino.in_waiting)
    
    left_area = 0
    right_area = 0
    
    # Draw ROI rectangles
    cv2.rectangle(frame, (roiLeft[0], roiLeft[1]), (roiLeft[0]+roiLeft[2], roiLeft[1]+roiLeft[3]), (0, 255, 255), 2)
    cv2.rectangle(frame, (roiRight[0], roiRight[1]), (roiRight[0]+roiRight[2], roiRight[1]+roiRight[3]), (0, 255, 255), 2)
    full_mask = cv2.inRange(frame, lower_black, upper_black)
    # Process Left and Right ROIs
    for idx, (x, y, w, h) in zip(["Left", "Right"], [roiLeft, roiRight]):
        roi = frame[y:y+h, x:x+w]
        hsv = cv2.cvtColor(roi, cv2.COLOR_RGB2HSV)
        mask = cv2.inRange(hsv, lower_black, upper_black)
        #full_mask = cv2.inRange(frame, lower_black, upper_black)

        contours, _ = cv2.findContours(mask, cv2.RETR_EXTERNAL, cv2.CHAIN_APPROX_SIMPLE)

        total_area = 0
        for cnt in contours:
            area = cv2.contourArea(cnt)
            if area > 50:
                offset_cnt = cnt + [x, y]
                cv2.drawContours(frame, [offset_cnt], -1, (0, 255, 0), 2)
                total_area += area

        if idx == "Left":
            left_area = total_area
        else:
            right_area = total_area

    # === STATE MACHINE DRIVING ===

    left_trigger = left_area < 100
    right_trigger = right_area < 100

    # ==========================
    # STATE: WALL_FOLLOW
    # ==========================
    if state == State.WALL_FOLLOW:
        # Debounce logic
        if left_trigger:
            trigger_count_left += 1
            trigger_count_right = 0
        elif right_trigger:
            trigger_count_right += 1
            trigger_count_left = 0
        else:
            trigger_count_left = 0
            trigger_count_right = 0

        # Enter CORNER_TURN_:
        if trigger_count_left >= TRIGGER_FRAMES or trigger_count_right >= TRIGGER_FRAMES:
            state = State.CORNER_TURN
            corner_start_time = now
            send(b'@M1630\n')
        else:
            # Normal wall following (Pd-control)
            error = left_area - right_area
            correction = int(Kp * error + Kd * (error - prev_error))
            new_servo_pw = center_servo - correction
            new_servo_pw = max(min_servo, min(max_servo, new_servo_pw))  # Clamp
            prev_error = error
            turning_angle = new_servo_pw
            cv2.putText(frame, f"{turning_angle}", (20, 50), cv2.FONT_HERSHEY_SIMPLEX, 2, (0, 255, 255)) 
            try:
                send(f'@S{new_servo_pw}\n'.encode())
                #print(new_servo_pw)
            except serial.SerialTimeoutException:
                pass

    # =========================
    # STATE: CORNER_TURN
    # =========================
    elif state == State.CORNER_TURN:
        elapsed = now - (corner_start_time if corner_start_time is not None else now)
        
        if trigger_count_right and trigger_count_left >= 5:
            send(b'@S90\n')
        
        if trigger_count_right >= 5:
            # turn RIGHT
            #arduino.write(b'@M1550\n')
            send(b'@S70\n')
            turning_angle = 70
            cv2.putText(frame, f"{turning_angle}", (20, 50), cv2.FONT_HERSHEY_SIMPLEX, 2, (0, 255, 255)) 
            #print("turn right")
            if left_area and right_area <= 50:
                send(b'@S90\n')
        
        if trigger_count_left >= 5:
            # turn LEFT
            #arduino.write('@M1550\n')
            send(b'@S110\n')
            turning_angle = 110
            cv2.putText(frame, f"{turning_angle}", (20, 50), cv2.FONT_HERSHEY_SIMPLEX, 2, (0, 255, 255)) 
            #print("turn left")
            if left_area and right_area <= 50:
                send(b'@S90\n')
                
        if left_area and right_area <= 50:
                send(b'@S110\n')

        # --- EXIT CONDITIONS ---
        recovered = False
        time_ok = elapsed >= MIN_CORNER_TIME

        if trigger_count_left >= 5 and time_ok:
            recovered = left_area > 1000
            
        if trigger_count_right >= 5 and time_ok:
            recovered = right_area > 1000
            
        if left_area and right_area <= 50:
                send(b'@S90\n')

        if recovered:
            state = State.WALL_FOLLOW
            prev_error = 0
            trigger_side = None
            trigger_count_right = 0
            trigger_count_left = 0
            #print("WALL_FOLLOW")
            send(b'@M1630\n')

        # === Orange Line Detection ===
    cv2.rectangle(frame, (roiOrange[0], roiOrange[1]), (roiOrange[0]+roiOrange[2], roiOrange[1]+roiOrange[3]), (0, 255, 255), 2)
    roi2 = frame[roiOrange[1]:roiOrange[1]+roiOrange[3], roiOrange[0]:roiOrange[0]+roiOrange[2]]
    roi_orange = frame[roiOrange[1]:roiOrange[1]+roiOrange[3], roiOrange[0]:roiOrange[0]+roiOrange[2]]
    hsv_orange = cv2.cvtColor(roi_orange, cv2.COLOR_RGB2HSV)
    orange_mask = cv2.inRange(hsv_orange, lower_orange, upper_orange)
    orange_pixels = cv2.countNonZero(orange_mask)

    if orange_pixels > 500:
        if not orange_line_detected and (time.time() - last_orange_time) > cooldown_seconds:
            orange += 1
            last_orange_time = time.time()
            print(f'{orange} orange lines detected.')
            orange_line_detected = True
    else:
        orange_line_detected = False  # reset when line leaves the ROI
    if orange >= 12:
        counter += 1
        print(counter)
        if counter >= 250:
            send(b"M1500")
            break

    cv2.rectangle(frame, (roiBlue[0], roiBlue[1]), (roiBlue[0]+roiBlue[2], roiBlue[1]+roiBlue[3]), (0, 255, 255), 2)
    roi2 = frame[roiBlue[1]:roiBlue[1]+roiBlue[3], roiBlue[0]:roiBlue[0]+roiBlue[2]]
    roi_blue = frame[roiBlue[1]:roiBlue[1]+roiBlue[3], roiBlue[0]:roiBlue[0]+roiBlue[2]]
    hsv_blue = cv2.cvtColor(roi_blue, cv2.COLOR_RGB2HSV)
    blue_mask = cv2.inRange(hsv_blue, lower_blue, upper_blue)
    blue_pixels = cv2.countNonZero(blue_mask)

    if blue_pixels > 400:
       if not blue_line_detected and (time.time() - last_blue_time) > cooldown_seconds:
            blue += 1
            last_blue_time = time.time()
            print(f'{blue} blue lines detected.')
            blue_line_detected = True
    else:
        blue_line_detected = False
    if blue >= 12:
        counter += 1
        if counter >= 275:
            send(b"M1500")
            break

    # === Debug Output ===
    cv2.imshow("Contours", frame)
    #cv2.imshow("orange", orange_mask)
    #cv2.imshow("blue", blue_mask)
    cv2.putText(frame, f"{turning_angle}", (20, 50), cv2.FONT_HERSHEY_SIMPLEX, 20, (0, 255, 255)) 
        
    if cv2.waitKey(1) == ord('q'):
        cv2.destroyAllWindows()
        break
    
    time.sleep(0.03)
# Cleanup
send(b'@M1500\n')
picam2.stop()
```

---
## Breakdown
The course for the open challenge can either be set up with a wide (100cm) or narrow (60cm) configuration. In the wide setup, the black walls are spaced farther and therefore can make the robots ROI's readings more difficult to detect the walls. The narrow configuration creates the opposite problem, and the walls occupy too much of the camera. Our primary navigation for the open challenge is with the camera. The camera captures multiple frames per second and stays on track by the ROI's. The ROI's are small rectangles placed at the edge of both sides. There is also a rectangular ROI in the middle of the screen used to detected the orange and blue lines when the robot makes its way around the map so it can stop when the three laps has been completed. The code is under "# === Orange Line Detection ===". So the side ROI's are used to detect black pixels, and the middle one is coded to detect blue and orange pixels. Once it has detected 12 blue or orange lines, the robot it will begin a counter of 250 which is enough time to let the robot finish the corner turn and stop in the correct spot in the middle of the course where it begun. 

## Modes
In our open challenge, our robot switches between two different modes in order to help our robot navigate the course. 

### Wall follow mode
Wall follow mode is the mode that the robot is in for most of the course. Wall follow mode follows the black walls along the side in order to make our robot travel straight. The robot scans the camera to ensure that there is an equal amount of black pixels in each ROI on either side. This allows the robot to travel perfectly in the middle of the path and prevents and zigzag pattern that may affect the efficiency.  

### Corner turn mode
The robot changes into corner turn mode when it stops detecting black pixels in one of the ROI's but not the other. This is when the robot knows to start turning in the direction of the ROI that doesn't have black. It stays in this mode for 3 seconds before turning back into wall follow mode, or until it begins to detect black in both ROI's again. This allows it to switch back and forth between the modes along the course with ease. 

# Obstacle Challenge 
## Overview
The obstacle challenge is a much more difficult version of the open challenge. In this challenge, there are red and green traffic pillars that the car must navigate around, as well as a parking lot. A red pillar indicates that the car should turn right to pass the pillar, and a green pillar indicates a left turn to pass the pillar. The car starts in a straight section or parking lot (for extra points) and must navigate 3 laps around the track avoiding obstacles. Once the 3 laps are finished the car can perform a difficult parallel parking maneuver for additional points. The parking lot is 1.5x the length of the car. In our case the parking lot will be about 24.5cm.
<br> <br>
**Youtube Link:** <br>
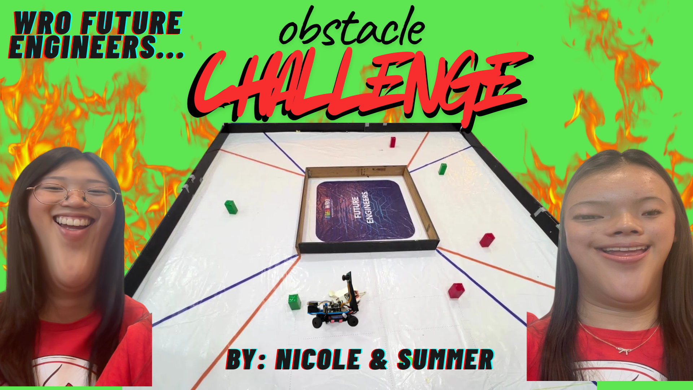
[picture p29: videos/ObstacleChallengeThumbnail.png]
Team Flight Obstacle Challenge 2026
 <br>
<a href="https://youtu.be/huQXz39QLw0">Team Flight Obstacle Challenge 2026 </a> 

---

### Game Map
<table>
  <tr>
    <td style="border: 200px solid black; padding: 5px;">
      
    </td>
  </tr>
</table>

## Code 
```
import sys
import time
import cv2
import numpy as np
import serial
from gpiozero import DigitalOutputDevice
import struct

from enum import Enum
from picamera2 import Picamera2

# ============================================================
# SERIAL COMMUNICATION
# ============================================================

def send(cmd):
    try:
        arduino.write(cmd)
    except serial.SerialTimeoutException:
        arduino.reset_output_buffer()
        try:
            arduino.write(cmd)
        except serial.SerialTimeoutException:
            print("Arduino timeout")

# STATES

class State(Enum):
    WALL_FOLLOW = 1
    CORNER_TURN = 2
    OBSTACLE_AVOID = 3

state = State.WALL_FOLLOW

# ARDUINO

arduino = serial.Serial('/dev/ttyACM0', 115200, timeout=1, write_timeout=0.05)
time.sleep(2)

# CAMERA

picam2 = Picamera2()
picam2.preview_configuration.main.size = (700, 480)
picam2.preview_configuration.main.format = "RGB888"
picam2.preview_configuration.controls.FrameRate = 30
picam2.configure("preview")
picam2.start()

# LIDAR

PORT = "/dev/ttyAMA0"
BAUD = 230400
PACKET_HEADER = 0x54
PACKET_LEN = 47
'''
# GPIO setup
LIDAR_POWER_PIN = 15  # BCM numbering
lidar_power = DigitalOutputDevice(LIDAR_POWER_PIN)

def find_packet_start(buffer):
    for i in range(len(buffer) - 1):
        if buffer[i] == 0x54 and (buffer[i+1] & 0xFF) == 0x2C:
            return i
    return -1

def parse_packet(packet):
    if len(packet) != PACKET_LEN:
        return None
    speed = struct.unpack_from('<H', packet, 2)[0] / 64.0
    start_angle = struct.unpack_from('<H', packet, 4)[0] / 100.0
    measurements = []
    for i in range(12):
        offset = 6 + i * 3
        dist = struct.unpack_from('<H', packet, offset)[0]
        confidence = packet[offset + 2]
        measurements.append((dist, confidence))
    end_angle = struct.unpack_from('<H', packet, 42)[0] / 100.0
    timestamp = struct.unpack_from('<H', packet, 44)[0]
    crc = packet[46]
    return {
        "speed": speed,
        "start_angle": start_angle,
        "end_angle": end_angle,
        "timestamp": timestamp,
        "crc": crc,
        "points": measurements
    }
'''
# STEERING

CENTER_SERVO = 90
MIN_SERVO = 70
MAX_SERVO = 140

KP = 0.009
KD = 0

prev_error = 0

# WALL FOLLOWING

WALL_THRESHOLD = 100
TRIGGER_FRAMES = 5
trigger_count_left = 0
trigger_count_right = 0

# LAP COUNTING

orange_count = 0
blue_count = 0

orange_line_detected = False
blue_line_detected = False

last_orange_time = time.time()
last_blue_time = time.time()

cooldown_seconds = 5

finish_counter = 0

# OBSTACLE VARIABLES

current_pillar_color = None

OBSTACLE_TRIGGER_AREA = 900

pillar_lost_counter = 0

# COLOR THRESHOLDS

    # walls

lower_black = np.array([0, 0, 0])
upper_black = np.array([180, 255, 100])

    # lap lines

lower_orange = np.array([88, 56, 107])
upper_orange = np.array([116, 224, 255])

lower_blue = np.array([0, 97, 88])
upper_blue = np.array([19, 255, 255])

    # HSV pillars

LOWER_RED = np.array([116, 162, 79])
UPPER_RED = np.array([131, 241, 234])

LOWER_GREEN = np.array([27, 116, 64])
UPPER_GREEN = np.array([74, 255, 141])

# ROIS

roiLeft = (20, 200, 150, 80)
roiRight = (550, 200, 150, 80)

roiOrange = (180, 280, 280, 70)
roiBlue = (180, 280, 280, 70)

#roiPillar = (0, 0, 640, 300)
'''
# START LiDAR SCAN

def interpolate_angles(start, end, count):
    angle_range = (end - start + 360) % 360
    step = angle_range / (count - 1)
    return [(start + i * step) % 360 for i in range(count)]

def main():
    try:
        # Power on the LD19
        lidar_power.on()
        print("LD19 powered ON via GPIO 15.")
        time.sleep(1.5)

        ser = serial.Serial(PORT, BAUD, timeout=0.1)
        buffer = bytearray()
        print("Listening for LD19 data...")

        while True:
            data = ser.read(256)
            if data:
                buffer += data
                while True:
                    idx = find_packet_start(buffer)
                    if idx == -1 or len(buffer) - idx < PACKET_LEN:
                        break
                    packet = buffer[idx:idx+PACKET_LEN]
                    buffer = buffer[idx+PACKET_LEN:]
                    parsed = parse_packet(packet)
                    if parsed:
                        angles = interpolate_angles(parsed["start_angle"], parsed["end_angle"], 12)
                        #print(f"\nSpeed: {parsed['speed']:.2f} RPM | Timestamp: {parsed['timestamp']} ms")
                        for i, ((dist, conf), angle) in enumerate(zip(parsed["points"], angles)):
                            #if abs(angle - 0.0) < 5:  # angles near 0° 
                            print(f"  Pt {i+1:02d}: {angle:.2f}°  {dist} mm  (conf: {conf})")
                    else:
                        print("Invalid packet")
            time.sleep(0.01)

    except KeyboardInterrupt:
        print("Interrupted by user.")

    finally:
        lidar_power.off()
        print("LD19 powered OFF.")

if __name__ == "__main__":
    main()
'''
# START MOTOR

send(b'@M1630\n')
send(b'@S90\n')

# FUNCTIONS

def clamp(value, minimum, maximum):
    return max(minimum, min(maximum, value))

def find_pillar(mask):

    contours, _ = cv2.findContours(mask, cv2.RETR_EXTERNAL, cv2.CHAIN_APPROX_SIMPLE)
    best_box = None
    largest_area = 0
    for cnt in contours:
        area = cv2.contourArea(cnt)
        if area < 900:
            continue
        x, y, w, h = cv2.boundingRect(cnt)
        if area > largest_area:
            largest_area = area
            best_box = (x, y, w, h)
    return best_box, largest_area

# MAIN LOOP

while True:

    frame = picam2.capture_array()

    # ========================================================
    # WALL DETECTION
    # ========================================================

    left_area = 0
    right_area = 0

    for name, (x, y, w, h) in zip(["Left", "Right"], [roiLeft, roiRight]):
        roi = frame[y:y+h, x:x+w]
        hsv = cv2.cvtColor(roi, cv2.COLOR_RGB2HSV)
        mask = cv2.inRange(hsv, lower_black, upper_black)
        contours, _ = cv2.findContours(mask, cv2.RETR_EXTERNAL, cv2.CHAIN_APPROX_SIMPLE)
        total_area = 0
        for cnt in contours:
            area = cv2.contourArea(cnt)
            if area > 600:
                total_area += area
        if name == "Left":
            left_area = total_area
        else:
            right_area = total_area

    # ========================================================
    # PILLAR DETECTION
    # ========================================================

    #px, py, pw, ph = roiPillar
    #pillar_roi = frame[py:py+ph, px:px+pw]
    hsv = cv2.cvtColor(frame, cv2.COLOR_RGB2HSV)
    red_mask = cv2.inRange(hsv, LOWER_RED, UPPER_RED)
    green_mask = cv2.inRange(hsv, LOWER_GREEN, UPPER_GREEN)
    red_box, red_area = find_pillar(red_mask)
    green_box, green_area = find_pillar(green_mask)

    pillar_box = None
    pillar_area = 0
    pillar_color = None

    if red_area > green_area and red_box is not None:

        pillar_box = red_box
        pillar_area = red_area
        pillar_color = "RED"

    elif green_box is not None:

        pillar_box = green_box
        pillar_area = green_area
        pillar_color = "GREEN"
        
    #if pillar_box is not None:
        #x, y, w, h = pillar_box
        #pillar_box = (x + px, y + py, w, h)

    # ========================================================
    # OBSTACLE PRIORITY
    # ========================================================

    if (state != State.OBSTACLE_AVOID and pillar_box is not None and pillar_area > OBSTACLE_TRIGGER_AREA):
        state = State.OBSTACLE_AVOID
        current_pillar_color = pillar_color
        pillar_lost_counter = 0

    # ========================================================
    # WALL FOLLOW
    # ========================================================
    if state == State.OBSTACLE_AVOID and pillar_box is not None:
        x, y, w, h = pillar_box
        pillar_center = x + w // 2
        frame_center = frame.shape[1] // 2
        offset = pillar_center - frame_center
        if current_pillar_color == "RED":
            #target_center = 150
            if pillar_center <= 150 and y > 250:
                state = State.WALL_FOLLOW
                avoid_heading_target = None
                current_pillar_color = None
        if current_pillar_color == "GREEN":
            #target_center = 530
            if pillar_center >= 530 and y > 250:
                state = State.WALL_FOLLOW
                avoid_heading_target = None
                current_pillar_color = None
    if state == State.WALL_FOLLOW:
        left_trigger = left_area < WALL_THRESHOLD
        right_trigger = right_area < WALL_THRESHOLD
        if left_trigger:
            trigger_count_left += 1
            trigger_count_right = 0
        elif right_trigger:
            trigger_count_right += 1
            trigger_count_left = 0
        else:
            trigger_count_left = 0
            trigger_count_right = 0
        if (trigger_count_left >= TRIGGER_FRAMES or trigger_count_right >= TRIGGER_FRAMES):
            state = State.CORNER_TURN
        else:

            error = left_area - right_area
            correction = KP * error + KD * (error - prev_error)
            servo = int(CENTER_SERVO - correction)
            servo = clamp(servo, MIN_SERVO, MAX_SERVO)
            prev_error = error
            send(f'@S{servo}\n'.encode())

    # ========================================================
    # CORNER TURN
    # ========================================================

    elif state == State.CORNER_TURN:
        if trigger_count_left >= TRIGGER_FRAMES:
            send(b'@S110\n')
            recovered = left_area > 1000
        else:
            send(b'@S70\n')
            recovered = right_area > 1000
        if recovered:
            state = State.WALL_FOLLOW
            trigger_count_left = 0
            trigger_count_right = 0
            prev_error = 0

    # ========================================================
    # OBSTACLE AVOID
    # ========================================================

    elif state == State.OBSTACLE_AVOID:
        if pillar_box is None:
            pillar_lost_counter += 1
        else:
            pillar_lost_counter = 0
            x, y, w, h = pillar_box
            pillar_center = x + w // 2
            frame_center = frame.shape[1] // 2
            offset = pillar_center - frame_center
            if current_pillar_color == "RED":
                target_center = 130
                '''if pillar_center <= 150:
                    state = State.WALL_FOLLOW
                    avoid_heading_target = None
                    current_pillar_color = None'''
            if current_pillar_color == "GREEN":
                target_center = 550
                '''if pillar_center >= 530:
                    state = State.WALL_FOLLOW
                    avoid_heading_target = None
                    current_pillar_color = None'''
            steering = int(CENTER_SERVO - 0.3 * (pillar_center - target_center))
            steering = clamp(steering, MIN_SERVO, MAX_SERVO)
            send(f'@S{steering}\n'.encode())
            cv2.rectangle(frame, (x, y), (x+w, y+h), (0,255,0), 2)
            #print(steering, pillar_center)
        if pillar_lost_counter > 8:
            state = State.WALL_FOLLOW
            avoid_heading_target = None
            current_pillar_color = None
            
    # ========================================================
    # LAP COUNTING
    # ========================================================

    roi_orange = frame[roiOrange[1]:roiOrange[1]+roiOrange[3], roiOrange[0]:roiOrange[0]+roiOrange[2]]
    hsv_orange = cv2.cvtColor(roi_orange, cv2.COLOR_RGB2HSV)
    orange_mask = cv2.inRange(hsv_orange, lower_orange, upper_orange)
    orange_pixels = cv2.countNonZero(orange_mask)
    #print(orange_pixels)
    if orange_pixels > 500:
        if (not orange_line_detected and time.time() - last_orange_time > cooldown_seconds):
            orange_count += 1
            last_orange_time = time.time()
            orange_line_detected = True
            print("Orange:", orange_count)
    else:
        orange_line_detected = False
    roi_blue = frame[roiBlue[1]:roiBlue[1]+roiBlue[3], roiBlue[0]:roiBlue[0]+roiBlue[2]]
    hsv_blue = cv2.cvtColor(roi_blue, cv2.COLOR_RGB2HSV)
    blue_mask = cv2.inRange(hsv_blue, lower_blue, upper_blue)
    blue_pixels = cv2.countNonZero(blue_mask)
    #print(blue_pixels)
    if blue_pixels > 500:
        if (not blue_line_detected and time.time() - last_blue_time > cooldown_seconds):
            blue_count += 1
            last_blue_time = time.time()
            blue_line_detected = True
            print("Blue:", blue_count)
    else:
        blue_line_detected = False

    # ========================================================
    # FINISH
    # ========================================================

    if orange_count >= 12 or blue_count >= 12:
        finish_counter += 1
        if finish_counter > 150:
            send(b'@M1500\n')
            break

    # ========================================================
    # DEBUG
    # ========================================================

    cv2.rectangle(frame, (roiLeft[0], roiLeft[1]), (roiLeft[0]+roiLeft[2], roiLeft[1]+roiLeft[3]), (0, 255, 255), 2)
    cv2.rectangle(frame, (roiRight[0], roiRight[1]), (roiRight[0]+roiRight[2], roiRight[1]+roiRight[3]), (0, 255, 255), 2)
    cv2.rectangle(frame, (roiOrange[0], roiOrange[1]), (roiOrange[0]+roiOrange[2], roiOrange[1]+roiOrange[3]), (0, 255, 255), 2)
    #qqqqcv2.rectangle(frame, (roiPillar[0], roiPillar[1]), (roiPillar[0]+roiPillar[2], roiPillar[1]+roiPillar[3]), (0, 255, 255), 2)
    cv2.putText(frame, f"{state.name}", (20,40), cv2.FONT_HERSHEY_SIMPLEX, 1, (0,255,0), 2)
    cv2.imshow( "frame", frame)
    #cv2.imshow("orange mask", orange_mask)
    #cv2.imshow("blue mask", blue_mask)
    #cv2.imshow("red mask", red_mask)
    #cv2.imshow("greenmask", green_mask)
    if cv2.waitKey(1) == ord('q'):
        break
    time.sleep(0.03)

# ============================================================
# CLEANUP
# ============================================================

send(b'@M1500\n')
picam2.stop()
cv2.destroyAllWindows()
```

## Breakdown
This code uses similar parts if the open challenge code, but has had added components to account for the extra pillars during the course, such as obstacle priority, obstacle avoid, and pillar detection. Obstacle priority ensures that the system verifies that a valid pillar bounding box is present and its pixel area exceeds OBSTACLE_TRIGGER_AREA (900 px). It forces the robot to turn to obstacle avoid mode and resets the counter of pixels. Pillar detection makes the camera converts frames to HSV color space and applies threshold masks to isolate red and green pillars, calculating their bounding box dimensions and total pixel area. If both colours are visible, the system prioritizes the larger contour, representing the closer obstacle, and outputs its bounding box, pixel count, and colours label to the state machine. The obstacle challenges uses the same system of counting the orange and blue lines around the course in order to stop in the right place. Since we are not going to be attempting the parallel park at the beginning and end, the robot is going to count to 250 and stop in the middle of the track, similar to the open challenge. 
## Modes
The obstacle challenge uses the same modes as the open challenge but it also incorporates a different mode called "Obstacle Avoid mode".  
### Obstacle avoid mode
The camera constantly scanning for red or green pillars that it detects into the camera. Once the camera detects 900 red or green pixels in frame, it is now considered an obstacle and the robot switches to obstacle avoid mode. It turns in the correct direction by controlling the servo motor to either go right around the red obstacle (it will stop  following the obstacle when it reaches an x value of 150 and a y value of 250) or left around the green one (when it reaches an x value of 550). It will go back to the either of the other modes once the obstacle is no longer detected.  

**State Machine Diagram describing how our program works:**

  <br>
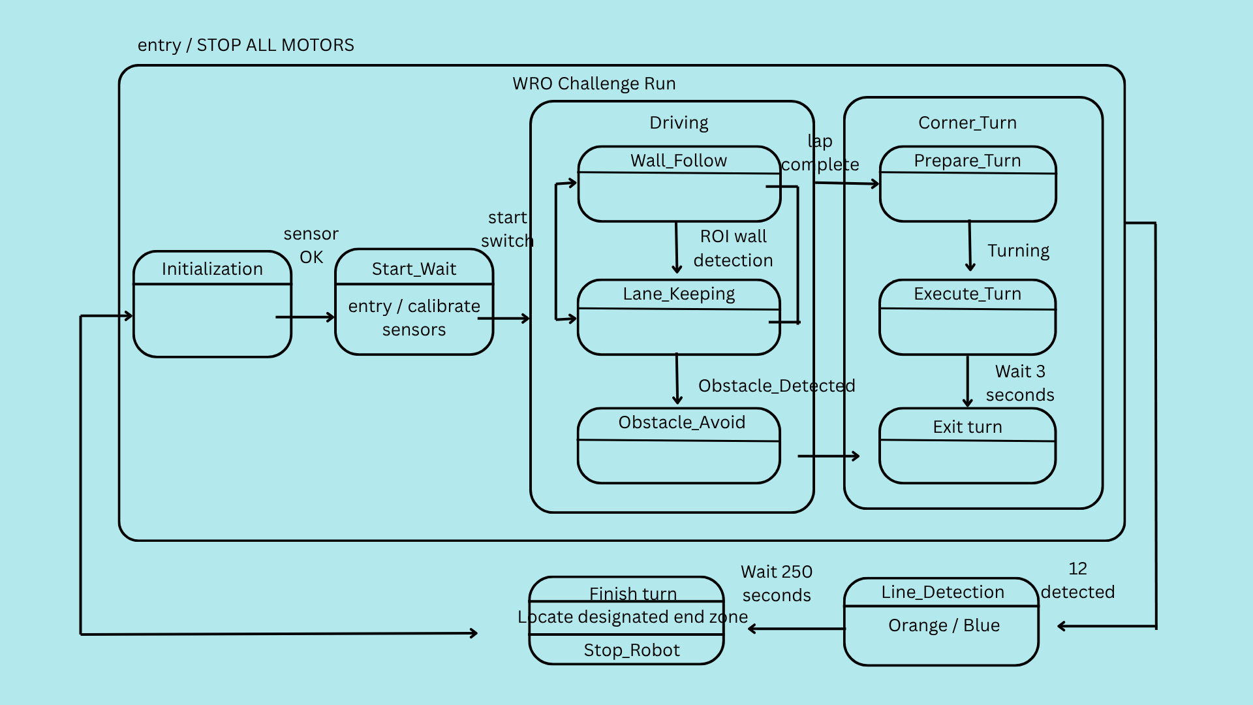
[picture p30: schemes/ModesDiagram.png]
 <br>

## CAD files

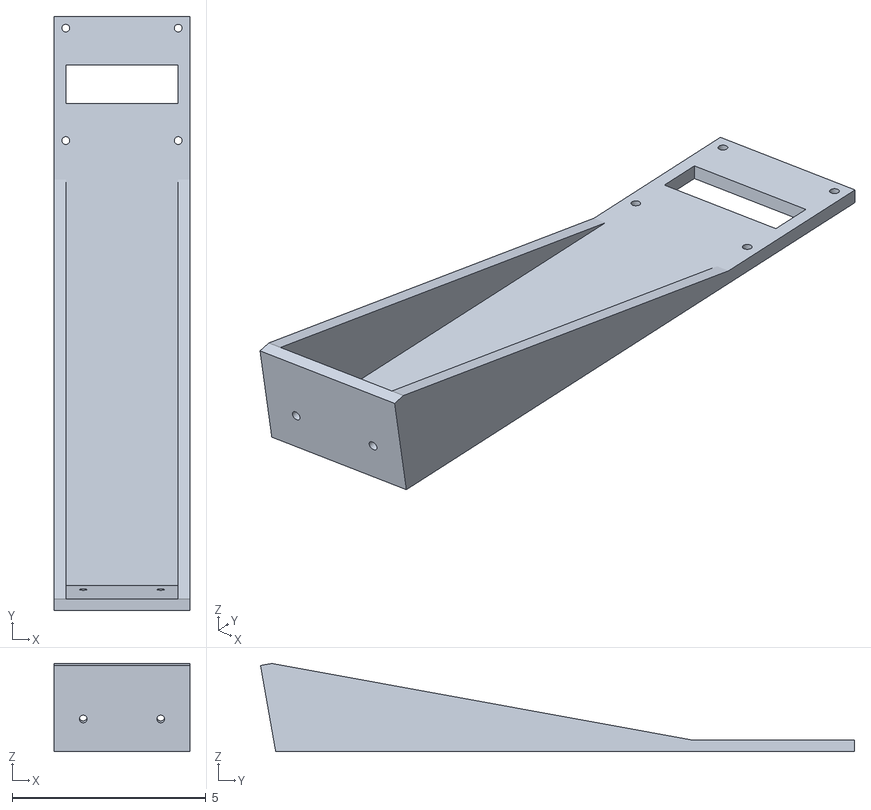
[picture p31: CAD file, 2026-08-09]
models/cameraV2.stl
3.50 x 15.3 x 2.27

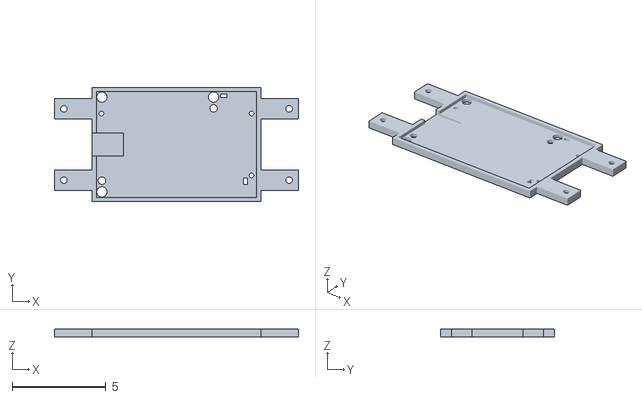
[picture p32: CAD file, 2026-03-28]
models/raspi.stl
13.0 x 6.10 x 0.4

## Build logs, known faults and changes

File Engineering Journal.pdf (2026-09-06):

Team Flight Engineering Journal

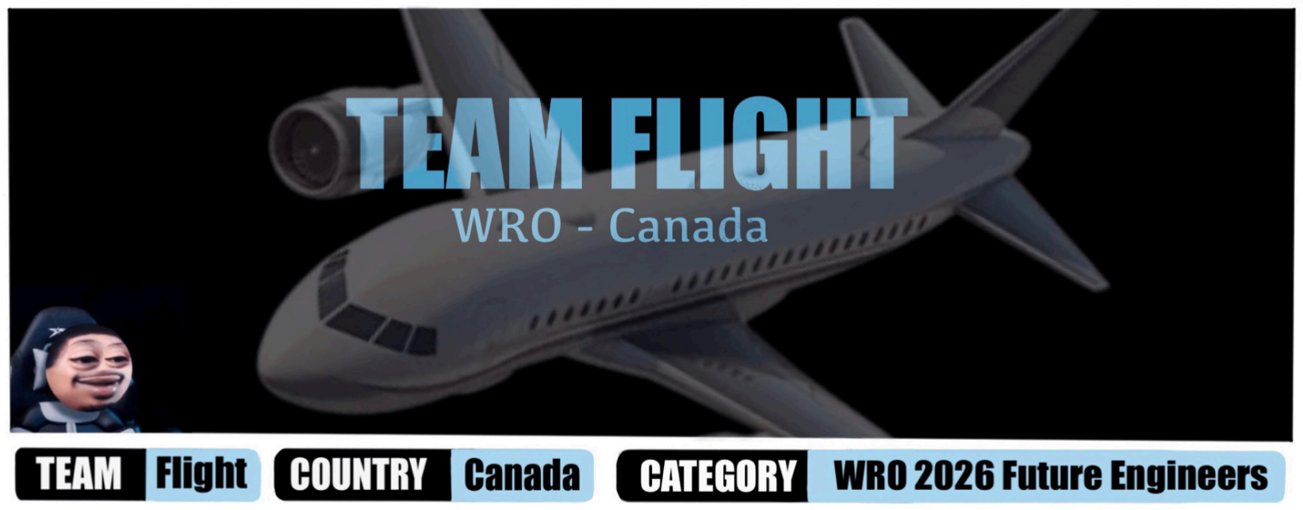
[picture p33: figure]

Summer Lu & Nicole Jin

WRO Future Engineers

Coach Rice

February 13, 2026

Table of Contents

Links | 3-4
Challenge and System Designs | 6-8
Camera | 6-8
Mechanical Iteration and Mobility | 9-11
Last Year’s Code | 9-10
Last year’s Open Challenge Code | 9-10
Navigation modes | 11-12
Power Analysis | 12-14
Subsystem Interaction | 12-13
Performance calculations | 13-14

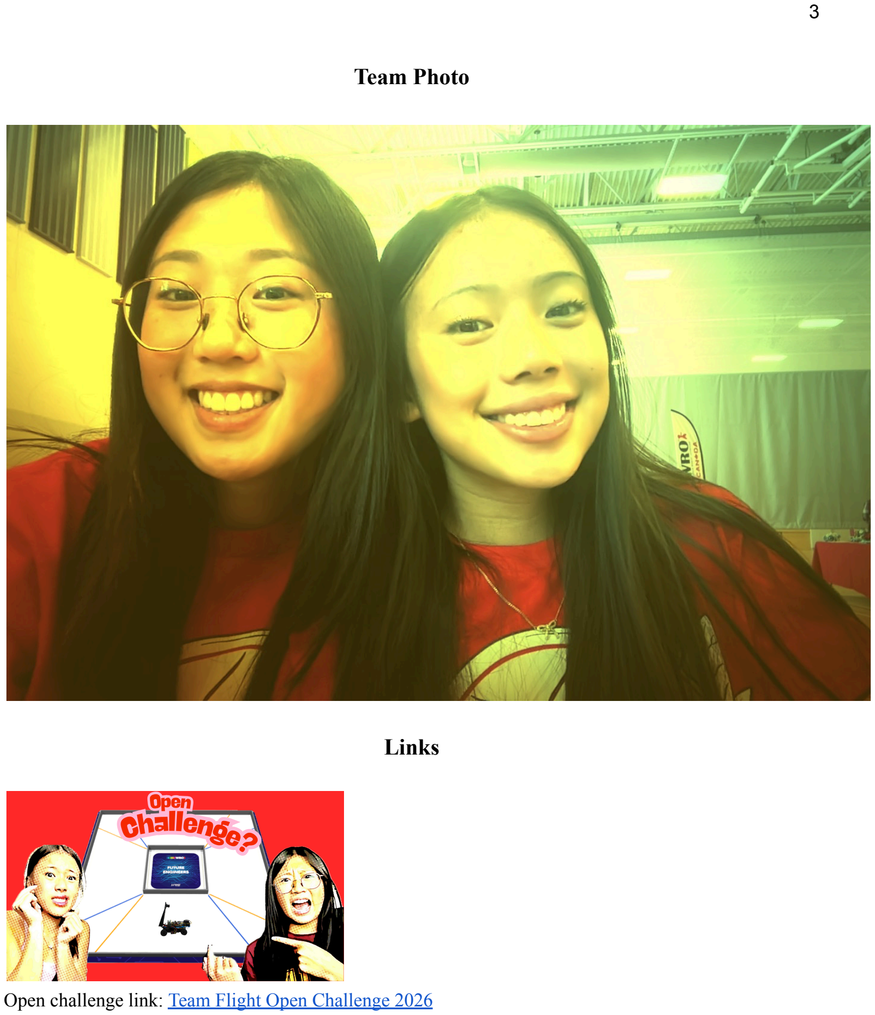
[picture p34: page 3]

Team Photo

Links

Open challenge link: Team Flight Open Challenge 2026 (https://youtu.be/M6A6o3CX_g0)

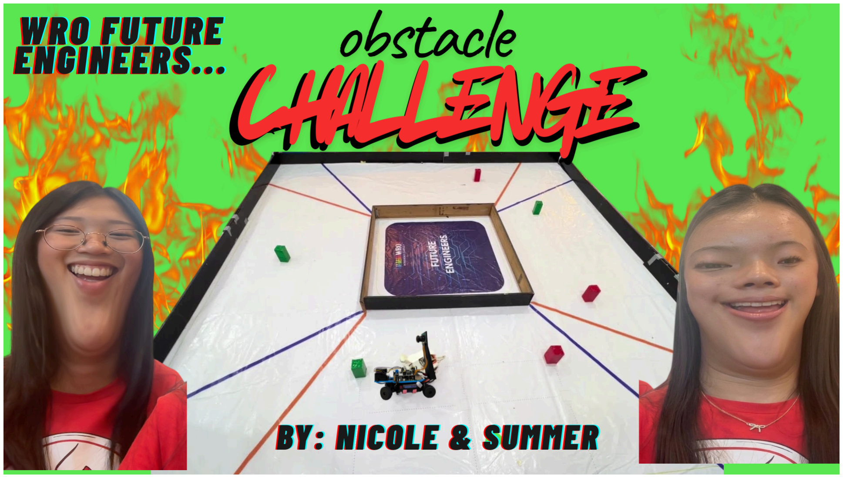
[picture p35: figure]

Obstacle challenge link: Team Flight Obstacle Challenge 2026 (https://youtu.be/huQXz39QLw0)

Introduction

Our vehicle is a lightweight, high-torque autonomous racer built on a custom brushless drivetrain. By integrating a Raspberry Pi 5 for vision and an Arduino Nano 33 BLE for real-time IMU stabilization, we achieved a balance between high-speed processing and agile physical response. Building a fully autonomous vehicle for the competition has been the most demanding engineering project of our high school career, pushing us far beyond basic robotics and into real-world control theory and computer vision. Our goal this year is to get a better score than last year and improve our knowledge and understanding on robotics. This journal documents the technical evolution, mechanical redesigns, and hard-earned lessons that transformed a failure-prone prototype into a stable, competitive robot.

Last year’s bugs

We also participated in last year’s WRO Future Engineers challenge. A lot of our robots have the same components as last year, but our design, chassis, layout has changed significantly. We also have additional added components, such as the LiDAR and the arduino. Our robot last year had a lot of bugs, we are trying to improve for this year's competition.
- Our 3D design had pegs that would connect the different levels of the robot, but since the pegs were so thin it would easily break.
- We had a LiDAR installed on our robot but never used it, making us unable to complete the obstacle challenge at all.
- Our chassis last year was not suitable for this challenge and would break constantly. Our design was also too high, making it heavy, hard to steer, and losing balance constantly.

Last year's design (2024-2025):

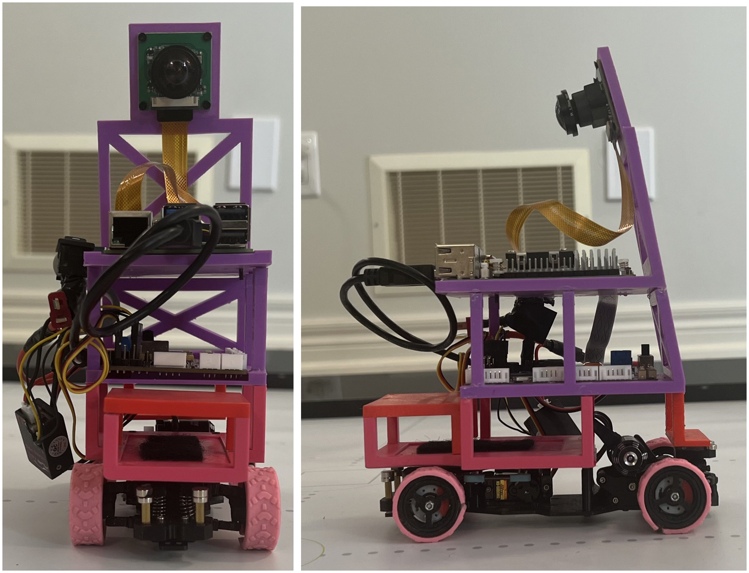
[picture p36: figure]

Upgrades

This is the improvements we made from last year to avoid the same mistakes from last year:
- December 12th, 2025: To separate and assemble the different layers of our robot, we used the plastic sticks attached already to our chassis and just made holes in our model holding the Raspberry Pi and the power regulator. To hold them in place we used retaining pins that also came with our chassis. This allowed our chassis to be lower to the ground and more stable when turning.
- November 23rd, 2025: Our chassis this year has a more stable base and grippier wheels. Better traction allows it to accelerate harder without losing control and maintain a steady speed when turning, making it better for precise tasks like parking and navigating pillars. We also cut part of our chassis so that our steering angle is much larger so it can turn sharper corners or avoid a pillar quickly. It also has much more space than our old chassis, allowing us to keep the battery, servo motor, and drive motor compact and out of the way.
- March 19th, 2026: Using new technology like the Arduino Nano provides benefits like how the robot manages timing, signal stability, and real-time responsiveness compared to last year's single board systems. The Arduino Nano operates on bare-metal architecture without an OS. Dedicated hardware timer registers generate 50 HzPWM signals with microsecond accuracy, ensuring smooth servo sweeps and consistent motor speed control without stuttering. A single board system could produce unpredictable micro delays when operating. If high-level vision pipelines, image segmentation, or path-planning code freeze or crash, the Nano runs an independent safety loop.
Issues about last year's code will be provided later on.

Challenge and System Designs

3D Chassis design:
For our chassis, we needed to 3D print out a platform for our raspberry pi and a ledge to hold up our camera. The following are our process into formulating so.

Camera:
November 25th, 2025 Design number 1:

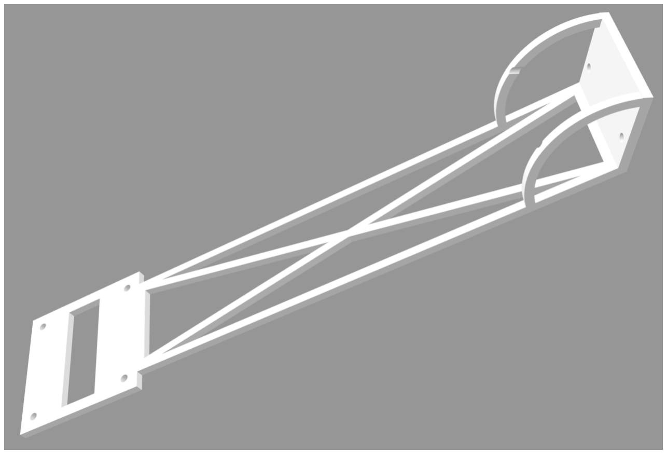
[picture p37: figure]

This is our original design for the camera, but it did not print properly because the support pillars were too thin and the round supporters caused some problems. We also realized that the screw holes were too close together and therefore couldn’t properly mount our camera into place.

December 5th, 2025 Design number 2:

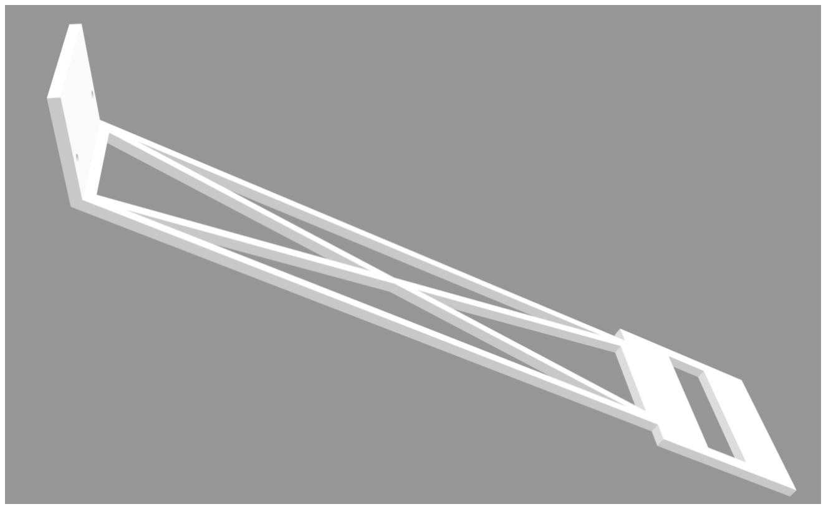
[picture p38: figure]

We removed the round supporters because they were too difficult to print. We came up with this new design, and simply just removed the round supporters. We also moved the screw holes slightly out to where it would match up with the screw holes on the camera. The pillars were not able to keep our camera stable and were too flexible, which would severely hinder the camera functions for the open and obstacle challenge.

December 16th 2025 Design number 3:

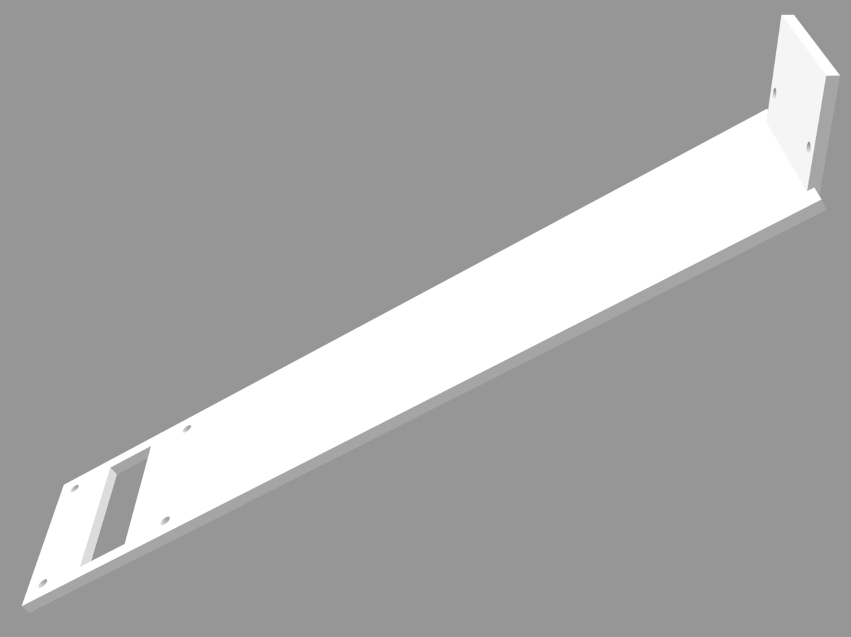
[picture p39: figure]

We replaced the thin pillars into a fully filled in wall. We tried to create a more lightweight design for our chassis, but settled for this instead. Even though this design made our 3D print heavier, it was enough to fully support the camera and display everything properly during the obstacle and open challenge. This 3D print design for our camera ended up not functioning because the angle was low. The robot did not see far enough in front of it so it could prepare to turn smoothly. It also was still too flexible and could bend easily when pushing a force on it.

December 19th, 2025 Design number 4 (Final Design):

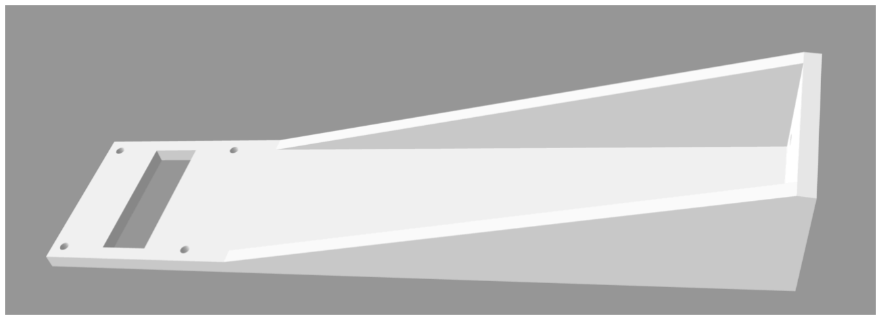
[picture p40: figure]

Our solution was to redesign our print so that the angle was closer to 90o and removed the gaps so it's more stable. This made the chassis print more heavy, but ensured that the camera was very stable when our robot was moving, printed properly, and portrayed everything in front of it for the obstacle and open challenge.

Raspberry pi:
December 5th, 2025 Design number 1 (Final Design not including LiDAR mount):

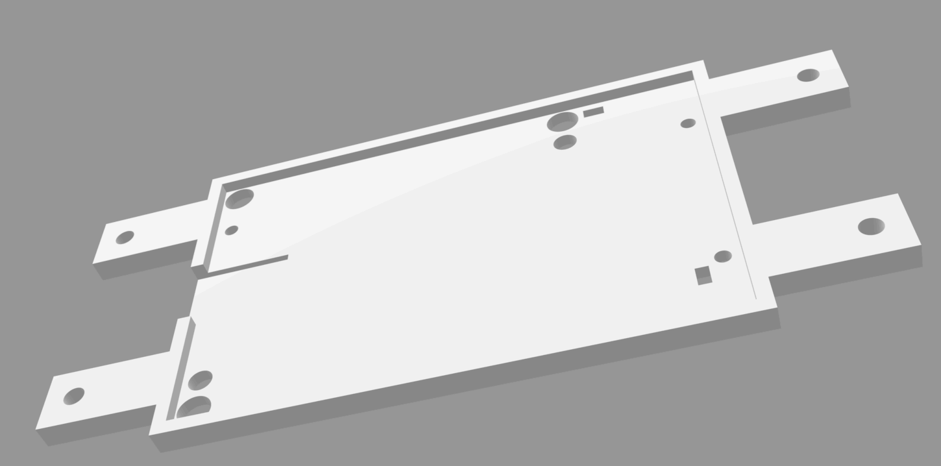
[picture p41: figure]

This is the original and final design for the raspberry pi platform. We measured every screw hole and the length to the chassis supporters so everything would fit into place. We ensured that the platform was high enough so that the motor and battery had enough space underneath. We did have to alter the printing dimensions a couple times, but never changed the original design.

Mechanical Iteration and Mobility Last Year’s Code:

Last year’s Open Challenge Code:
March 19th, 2026: We first tried to upload our open challenge code from the previous year. We quickly realized multiple problems from the code and made several changes.
- We needed to upload based on this year's setup. We aren’t using the rrc.Board from hiWonder anymore. The obsolete code below was removed:

import ros_robot_controller_sdk as rrc

board = rrc.Board()

board.set_rgb([[1, 0, 0, 0], [2, 0, 0, 0]])

def check_node_status():
command = 'source /home/ubuntu/.zshrc && ros2 topic list'
result = subprocess.run(
['docker', 'exec', '-u', 'ubuntu', '-w', '/home/ubuntu', 'MentorPi', '/bin/zsh', '-c', command], capture_output=True, text=True)
res = result.stdout
return '/ros_robot_controller/button' in res
- All serial writes using the format arduino.write(b'@M1600') we made sure didn’t have a \n terminator. If the Arduino firmware expects newline-terminated messages, the commands will buffer up and never be parsed.
- We included two modes. Our code only used one single P controller handling both straight sections and corner sections. In the straight section, we wanted a more gentle correction and a higher speed. In the corner, we needed more aggressive steering and likely a slower speed to avoid overshooting. Since a single p-controller can’t do both well (being too sluggish on the corners after being tuned for straight and being twitchy after being turned for corners), we needed to change it so our code uses two modes. We made our car drive faster when both ROI’s detected black and have a more gentle kp. When only one ROI detects black, we slow down and turn until both ROI’s detect black.
- We added a derivative on the error to reduce oscillation.
- Our code had a shared detection flag between the orange and blue detention. We needed to change them to two separate flags (orange_line_detected and blue_line_detected). This is so when an orange line is set to true, the blue direction else branch does not immediately reset to false (and vice versa), helping us count rotations better during the open challenge.
- The “else: line_detected = False” is inside the “if orange_pixels > 100 block”, meaning line_detected only resets when pixels are still above threshold. To fix this, it now resets when the line leaves the ROI. Same with blue.

- In our code, we sent too many commands to the arduino. In every frame we sent both @M1600 and @S{pw} (60 commands/sec at 30 fps). To fix this, we send commands only when a value needs to be changed.
- We used computed contours_orange and contours_blue, but we didn’t use it, so we removed the findContours calls to save CPU.
Our new and updated open challenge code is provided in the READ ME.

Last Year’s Obstacle Challenge Code:
The previous year, we did not complete the coding of our obstacle challenge. This year, we are planning to improve and navigate around the red and green pillars on the corresponding side. We are going to progress into working the obstacle challenge and improving the open challenge for our new design. We are also going to incorporate new technology introduced to us this year, like the Arduino Nano.

This Year’s Code:

August 23rd, 2026: In this year's new and updated code, we incorporated several targeted engineering strategies across the open and obstacle challenges to optimize autonomous track navigation, obstacle avoidance, and system safety. For the Open Challenge, stability and reliable cornering are achieved by requiring a multi-frame debouncing check (TRIGGER_FRAMES = 5) before transitioning into corner turn mode, protecting the system from false state changes caused by track glares or shadows. While in wall follow mode, a proportional controller (kp = 0.009) calculates the differential between left and right wall pixel areas to continuously maintain a centered trajectory, while active cornering locks in fixed steering angles until the opposite wall area recovers above 1000 pixels. Lap tracking is similarly stabilized using a 5 second software cooldown timer (cooldown_seconds = 5) across the orange and blue line ROIs to eliminate double-counting, automatically bringing the robot to a complete stop (@M1500) once 3 laps are registered. For the Obstacle Challenge, the vision pipeline assigns top execution priority to pillar detection whenever a contour exceeds 900 pixels, overriding standard wall-following logic to prevent imminent collisions. If both colored markers enter the frame simultaneously, an area arbitration check prioritizes the larger contour to navigate around the closer obstacle first, using a dynamic proportional steering calculation based on the pillar’s horizontal centroid offset relative to target positions (x=130 for red and x=550 for green). To handle sudden visual loss during aggressive bypass maneuvers, a temporal fallback counter (pillar_lost_counter > 8) safely reverts the system to wall follow mode if the pillar leaves the camera frame, while all output servo angles are continuously run through a physical clamping function (MIN_SERVO=70, MAX_SERVO=140) to safeguard mechanical linkages against over-extension.

Mobility reasoning:
July 16th, 2026: Throughout the obstacle challenge we changed our kp to 0.009 instead of 0.0075 because this changed value makes the navigation the smoothest in order to complete the challenge in time and with efficiency. The 20% increase forces the servo to react faster when entering sharp corners or quick changes around pillars. It reduces tracking errors, returning back on track faster, especially with the unexpected added obstacles during the competition. It also allows the different modes to have enough time to switch smoothly and with ease.

Mechanical Iteration progression:

At the beginning, the steering assembly utilized stock plastic linkages with a direct servo. Under aggressive proportional corrections in wall follow mode, mechanical play in the stock ball joints caused 2

0–3⁰ of steering slope. This slope resulted in subtle front-wheel oscillation flutter on high-speed straightaways, skewing our visual camera alignment and causing false wall-distance readings. We redesigned the front steering linkage, replacing the stock rods with custom 3D-printed rigid tie-rods mounted to an STL bracket, while repositioning the steering servo 5
mm lower on the chassis deck. Additionally, we cut restricting areas off the chassis in order to make space for the steering angle to widen. Shifting weight toward the rear wheels increased rear tire traction during rapid acceleration, reducing wheel slip and stabilizing straight-line camera ROI tracking.

Navigation Modes
Below are the different navigation modes our robot uses and explanations/reasonings to the chosen values and concepts.

Wall follow mode:
The vision pipeline evaluates two mirrored ROI’s to monitor the outer black boundaries. By calculating the ratio of detected black pixels in each ROI, the software computes a real-time tracking error. Balancing visual weight across both frames prevents harsh overcorrections, replacing chaotic zigzagging with smooth, linear tracking. Keeping the vehicle dynamically locked to the lane centerline maximizes clearance on both sides, mitigating collision risks and saving vital battery power through reduced steering drag.

Corner turn mode:
The visual imbalance as a state trigger allows the robot to instantly recognize a track corner without needing complex, computationally expensive scene reconstruction. The asymmetry directly dictates the turning trajectory. This removes ambiguity and eliminates latency between corner detection and turn execution. The spatial trigger prevents over-turning once the vehicle aligns with the new straightaway, while the temporal timeout acts as a failsafe to keep the vehicle moving forward if track reflections or wall gaps briefly disrupt visual tracking.

Obstacle avoid mode:
Requiring a minimum contour area of 900 pixels acts as a spatial noise filter. It prevents the system from triggering false-positive obstacle states when distant pillars, wall reflections, or background visual artifacts briefly appear in the camera's field of view. The robot only reacts when a pillar is close enough to present an immediate collision risk. Red pillar values being X≥150,Y≥250 allows the robot to wait for the pillar's bounding box center to reach these threshold coordinates and ensures the robot's rear wheels have physically cleared the right side of the red obstacle before straightening out. Same with the green pillars as well.

Power Analysis
Subsystem interaction:

In order to control our robot, it undergoes subsystem interactions to transfer its perceptions to the motor.

(Camera/LiDAR) —>(Raspberry Pi 5)—>(Serial/UART)—>(Arduino Nano)—>(ESC & Servo)
(Perception) | (Path Planning) | (Motor Control) | (Actuation)

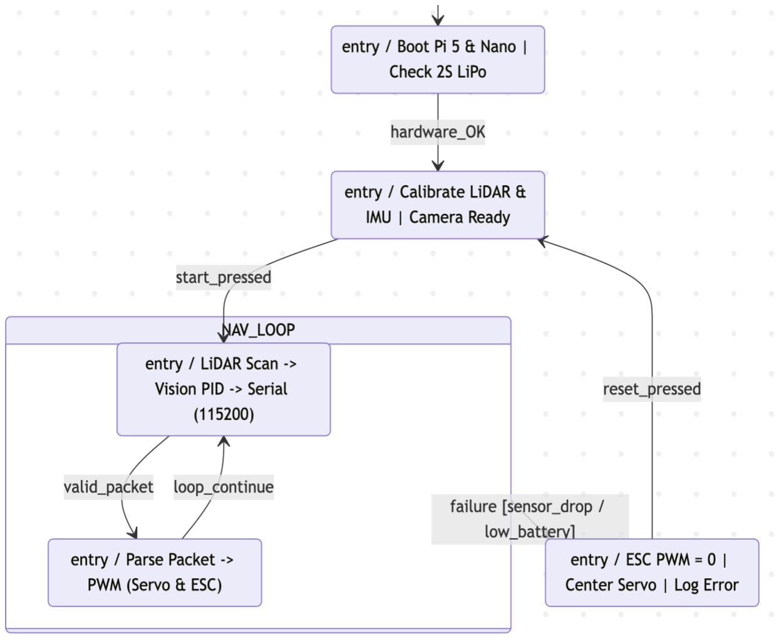
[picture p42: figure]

### 1. Power distribution & Signals

The power subsystem provides clean logic power while supplying high current to the drivetrain without inducing voltage sag or brownouts on the Raspberry Pi 5. The Gens Ace 2S LiPo connects directly to the drive motor’s ESC. The converter taps off the 2S battery to supply a stable 5V/5A rail directly to the Raspberry Pi 5 (via USB-C or GPIO power pins). The Arduino Nano draws its power directly from one of the Raspberry Pi 5’s USB ports, ensuring logic ground is shared across both computing boards.

### 2. Perception & Path Planning

The Pi processes these arrays to compute wall distances on both sides of the vehicle, detecting open corridors, 90∘ track turns, and outer boundary walls. The camera captures color frames on a background thread. OpenCV processes these frames using HSV color masks or light object detection models to spot red and green traffic pillars, estimating their bounding box positions and distance relative to the front bumper. The error passes through the tuned Proportional-Derivative loop (Kp=0.009) to derive the exact target steering angle and target motor velocity.

### 3. Inter Communication

The Arduino Nano’s serial buffer reads non-blocking incoming characters until the newline character (\n) is reached. A lightweight string parser converts the ascii numbers into integer variables inside the microsecond loop.

### 4. Microcontroller Execution

The servo receives high-frequency timing directly from the Nano’s hardware timer register, preventing steering flutter. The target velocity value is converted into standard RC ESC signals (1.0 ms full reverse / neutral brake at 1.5 ms / 2.0 ms full forward).

### 5. Automated Failsafe loop

The Arduino Nano tracks elapsed time since the last valid serial packet using millis(). If no command arrives from the Pi for more than 200 ms (due to a software crash, freeze, or disconnected cable), the Nano automatically resets motor PWM to neutral (SPEED:0). If the Pi detects LiDAR signal drops, battery voltage falling below 7.0V, or an emergency wall proximity threshold (<5 cm), it transmits an immediate override packet (STEER:0,SPEED:0\n), forcing the Arduino to lock steering straight and apply active motor braking.

Performance Calculations

August 16th, 2026: To optimize our 1:24 scale rear-wheel-drive (RWD) platform for the WRO track layout, we selected a 3450 KV brushless motor powered by our 2S LiPo battery (7.4V nominal). At full charge (8.4V peak), the motor reaches a theoretical maximum unloaded speed of approximately 28,980 RPM:

RPMmax=3450 KV×8.4 V=28,980 RPM

Accounting for our drivetrain gear reduction and wheel diameter, this KV rating provides a top speed capable of completing a 3-minute match run well within track requirements while keeping motor temperatures low. Lower KV brushless options lacked the acceleration burst needed to rapidly recover speed after sharp turns or aggressive obstacle bypasses. Conversely, higher KV motors produced excessive wheelspin on our low-friction chassis tires and drew high current spikes, risking voltage brownouts on our logic rails. The 3450 KV motor represents the optimal balance of immediate low-end acceleration out of corners and controllable top-end velocity on straightaways.

Conclusion

Through iterative hardware refinement and several improvements, our 1:24 scale autonomous platform successfully fulfills all technical requirements for the both challenges in the WRO competition. By pairing the high-level computer vision and spatial processing of the Raspberry Pi 5 with the deterministic, real-time actuation of the Arduino Nano, the system achieves stable wall-following, reliable corner transitions, and responsive pillar avoidance. Comprehensive power management, multi-frame vision debouncing, and custom mechanical linkage upgrades ensure high operational reliability across both the Open and Obstacle challenges. Detailed build logs, system schematics, and final high-resolution photographs of the completed robot assembly are available in the project's README on Github.

Repository Link :https://github.com/nicolejin16/Flight/tree/main

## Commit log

2026-02-20 Update README with physical qualities for motors
    Added physical qualities tables for drivemotor and servomotor sections.
2026-02-20 Add test.txt to MaterialPhoto directory
2026-02-20 Move material photos into material photos file
    move battery.jpg
    move Drivemotor.html
    move Servomotor.jpg
2026-02-20 Fix spelling of LiDAR in README
    Correct spelling of 'LIdar' to 'LiDAR' in the README.
2026-02-20 Refactor battery and motor sections in README
    Removed redundant table tags and added explanations for motor and ESC choices.
2026-02-20 Add product choice rationale for camera and Raspberry Pi
    Added sections explaining the choice of the 5/Zero Camera Module and the Raspberry Pi 5 Kit.
2026-02-20 Add Material Photo
    Add ArduinoNano.jpg
    Add Camera.jpg
    Add ESC.jpg
    Add LiDar.jpg
    Add PowerRegulator.jpg
    Add RaspberryPi5.jpg
    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
2026-02-20 Update product images and details in README
    Updated images and product details in the README file, including new entries for LiDAR and corrections to existing product information.
2026-02-20 Fix spelling of LiDAR to LiDar in README
    Corrected the spelling of 'LiDAR' to 'LiDar' in multiple sections.
2026-02-20 Resize battery image in README
2026-03-08 Update README with product details and specifications
    Added detailed product specifications and reasons for choosing the DC AC rocker switch and power supply expansion board. Included additional information about current ratings, operating voltage, and 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
2026-03-28 Add 3d model for Raspberry Pi
    add "models" folder and raspberry pi gcode.
    [raspi.stl]
2026-04-26 Update README with power ratings and wiring details
    Add power ratings table and additional details about components.
2026-04-26 Fix section title and improve drive system description
    Corrected section titles and improved clarity in the 'Steering and Drive system' section. Fixed typos and added details to enhance understanding of the drive system.
2026-05-03 add Arduino Code
2026-05-24 Implement obstacle challenge logic and camera setup
    Added code for obstacle challenge navigation and camera integration.
2026-08-09 add chassis photo
2026-08-09 Update 3D design section with embedded model viewer
    Replaced static image links with an embedded iframe for the Raspberry Pi model and retained the image link for the camera model.
2026-08-09 Replace iframe with image for Raspberry Pi model
    Updated embedded model link to an image for better display.
2026-08-11 Fix spelling of 'LiDar' to 'LiDAR'
    Corrected spelling of 'LiDar' to 'LiDAR' throughout the document.
2026-08-16 Revise team member ages and enhance README formatting
    Updated team member ages and improved formatting for battery specifications and additional information.
2026-08-16 add wiring map and photos of robot
2026-08-17 Update README with interactive models and fabrication info
    Added information about interactive models and 3D printing details.
2026-08-19 Update button image and replace product link
2026-08-19 ss of camera and raspberrypi models
2026-09-05 Enhance README with obstacle challenge details
    Added detailed descriptions for obstacle challenge modes and camera functionality.
2026-09-05 Document LiDAR plans for parking in README
    Added a section about LiDAR usage for parking in the obstacle challenge.
2026-09-05 Fix typos and update LiDAR parking section
    Corrected typos and improved formatting in the README.
2026-09-10 update arduino code to include led
